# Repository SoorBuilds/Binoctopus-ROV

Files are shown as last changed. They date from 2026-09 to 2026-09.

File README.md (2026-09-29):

Screenshot 2026-09-12 at 11 26 09 PM

# Binoctopus-ROV

A stereoscopic underwater FPV drone

If you have ever wanted to explore the underwater world without getting wet, you can understand my motivation for designing this! I love the water and pretending to be a fish, but due to an ear problem I cant dive any deeper than 2m underwater :(
I knew I wanted to make an underwater drone to combat this issue, but none of the tutorials I could find online looked any good. They just WEREN'T IMMERSIVE! I set out to design a low budget, yet extremely immersive ROV and this design is my result so far. I expect it will need further iteration, but so far, My idea is to take two gopros and use them in webcam mode to stream 1080p60fps low latency up to the surface through a companion computer rasberry pi. Here is an image of the housing I designed for the gopros to be encased in an acrylic pipe with a custom 3d printed encap potted with epoxy for hypothetical pressure resistance up to 8.5 bar (85m underwater): 
Screenshot 2026-09-13 at 12 14 38 AM
But hold on... Why have two? 
After a ton of research into the cheapest way to get the best immersion on a tight budget, I discovered the Stereoscopic FPV community. FPV flying drone enthusiasts swear by a dual camera approach so that you can get depth perception, the same way that your two eyes do. By streaming the feed from one camera into one of the screens on a VR headset, and the right into the right for example, you would end up with a VERY natural feeling viewing experience, almost like looking through your own eyes.
Image of my oculus quest VR heasdet I will use to view the stereo video feeds:


Of course, this stereo vision needs to be paired with High resolution and low latency, both of which are usually very costly.
But there must be a cheap solution to this too... right?
Old Gopros! 
Old gopros are a proven low budget tool for high definition camera systems. They are able to handle all of the video compression by themselves and then transmit it either through WiFi or USB cable. Of course, for our underwater applications WiFi will not work, so cable it is.
Screenshot 2026-08-31 at 11 19 13 AM
Next up was the propulsion system!
For this i designed a custom thruster case to fit my 980kv sunnysky BLDC motors. I wanted to be able to just copy and paste the thrusters so that I could easily model the whole thing around the same repeating geometry. For this reason I decided to make it a the shape of a barrel that can easily be replaced if anything corrodes or breaks.



My test of the thruster at low speed in my bathroom sink:

https://github.com/user-attachments/assets/cb4b14ec-2ffa-4109-a6d4-e576eac1fb48

I want this drone to be as immersive as possible, it should feel like you are a fish!
This is why I decided to go with a vectored 6 degrees of freedom configuration. I tried to replicate the configuration from the FiFish v6, a $1700 ROV that manages to achieve 6 independant degrees of movement with only 6 motors!
Here is my attempt at replicating the configuration: 
Screenshot 2026-09-13 at 12 23 29 AM
Next up was the electronics!

Screenshot 2026-09-13 at 10 51 15 AM

This was the part I was dreading most and thankfully, I was able to find a good electronics schematic for a similiar project to what I was trying to do and I modified it to fit my design.
For the battery, I decided to go with a 3s3p custom pack using 9 lithium 18650 cells. Connected to the battery is a ____ A fuse and a pixhawk power sense module for extra safety.
For the Control system I went with the proven Pixhawk flight controller which allows me to control the complicated thruster configuration with ease through a program handled by the pixhawk. The pixhawk also reads the I2C protocol coming from a Depth sensor module which will come in very handy. Also, it acts as a safety mechanism allowing me to see the battery voltage, current draw, and it has a built in failsafe if the battery current goes too high.

Screenshot 2026-09-13 at 10 56 53 AM

The Rasberry pi is used as the companion computer to the pixhawk flight controller, it communicates through an ethernet cable to the surface computer giving the Camera feeds, depth information, power sensor information, IMU information, and temperature. 
To power the motors I use a 4 in 1 HackRC drone ESC and 2 single Littlebee ESCs, each channel is rated for 25A.
I also decided to mount a small 3d printer fan because these ESC's will get HOT!
Finally I wanted to include 4 LED's so I also mounted the drivers into the bottom of the configuration. 
Heres the power schematics i'm using
Screenshot 2026-09-27 at 6 01 12 PM

The wires are then routed out of the 3d printed endcap, soldered together and then the solder joint is potted in epoxy for maximum pressure rating, then the ethernet cable goes into a WEIPU female connector to attach to the ethernet cable tether going up to the surface!

Thats about it for the electronics
After designing this I went through it with my friends dad who is an Electrical Engineer. He approved!

All of the electronics fit inside of a 80ID x 90OD acrylic pipe that is 320 mm long
The endcaps are 3d printed and the cables are passed through with solder joints to stop capilary action up the cable insulation. Then the whole endcap, cable joints included, is potted in epoxy 

Screenshot 2026-09-13 at 11 01 25 AM

The part I was most looking forward to as an aspiring designer was the shell:
Screenshot 2026-09-12 at 2 51 10 PM
This took me A LOT of time, about two weekends worth of not touching grass but I think it was worth it because the result is a hydrodynamic, easy to assemble (hopefully) very solid design that will print in a standard 256^3 mm 3d printer bed! 
The hardware needed for as
embly is minimal, about 50 m3 bolts and heat set m3 brass inserts 
As for the assembly, I designed it to be as easy as possible. All of the thrusters connect to the shell in 4 places so start by inserting heat set inserts into your thrusters, then screw
How the horizontal thrusters will screw into the shell:

https://github.com/user-attachments/assets/931fc479-a999-401c-849b-3841b58536d0

I also decided to go with a vectored LED lighting fixture for 4 5W LEDs that should give a wide floodlight when descending past the daylight or diving at night. These LEDs will not just be on or off, but they can be controlled by a PWM signal provided by the Pixhawk

Screenshot 2026-09-13 at 10 39 18 AM

The tether connects to the shell by a rear mounted WEIPU connector: 
Screenshot 2026-09-13 at 10 47 37 AM

Because the shell was too big to print in one piece, it divides nicely into a rear, and two halves of the front. Everything is secured with M3 screws that will make for a very sturdy connection between the different pieces: 

https://github.com/user-attachments/assets/647f90c3-3dfa-40e7-80a8-27e3c8544850

Thats it for the shell! 
For the software, I will just be using the standard Ardusub firmware downloaded onto the pixhawk flight controller, for the surface computer I will use QGround control to be able to control the whole thing with my PS4 controller and view the camera feeds in my oculus quest headset!

My personal BOM (what I need to build this, I have most if it already) [Binoctopus ROV V1 BOM - What I need BOM(2).csv](https://github.com/user-attachments/files/32712083/Binoctopus.ROV.V1.BOM.-.What.I.need.BOM.2.csv)

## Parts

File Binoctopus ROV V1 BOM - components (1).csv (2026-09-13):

 | Name | Cost per unit | Shipping to US | photo | primary source | source 2 | source 3
 | 3x Molex male connector 20pin + pins | 5.32 | 0.00 |  | https://www.amazon.com/Molex-Circuits-Receptacle-Terminals18-24-Mini-Fit/dp/B079DCBCBZ/ref=sr_1_4 | https://www.amazon.com/Molex-Circuits-Receptacle-Terminals18-24-Mini-Fit/dp/B079DCBCBZ | https://s.click.aliexpress.com/e/_omMvDhG
 | 2x big oring (80 OD X 70 ID) | 5.75 | 4.44 |  | https://www.aliexpress.us/item/3256801511930688.html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 | https://s.click.aliexpress.com/e/_DBGTF93 | https://www.amazon.com/Mr-Ring-5X60-Metric-Viton/dp/B091B9QRPZ
 | acrylic pipe 80x70mm 250mm length | 55.00 | 18.48 |  | https://www.ebay.com/itm/358193843642?_skw=acrylic+tube&itmmeta=01KXMQHSF01GY1WHCQRDGK03KN |  | for some EU countries
 | Gopro Hero 12 x 2 on facebook marketplace | 250.00
 | USB C breakout board | $8 | 0.00 | 0.00 | https://www.amazon.com/MTDELE-Connector-Adapter-Breakout-Compatible/dp/B0F3WWTX78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 | https://www.amazon.com/MTDELE-Connector-Adapter-Breakout-Compatible/dp/B0F3WWTX78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
 | Cooling fan | 12.00 |  |  | https://www.aliexpress.us/item/2251832621295326.html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
 | Pressure sensor GY-MS5837 | 19.47 | 0.00 |  | https://s.click.aliexpress.com/e/_DelXMPr | https://s.click.aliexpress.com/e/_DlrplMZ | https://www.amazon.com/GY-MS5837-Waterproof-Pressure-Sensor-Module/dp/B09MKL4G1Y
 | 6x Sunnysky motor (980KV) | 80.00 | 0.00 |  | https://s.click.aliexpress.com/e/_DcYTy0v | slightly faster delivery | https://s.click.aliexpress.com/e/_DEd4fLL
 | 12x 5 gram metal weights | 1.80 | 0.00 |  | https://s.click.aliexpress.com/e/_DFjnm9J | https://www.amazon.com/Supply-Steel-Stick-Wheel-Weights/dp/B0068EQ9W0 | https://s.click.aliexpress.com/e/_DEcy23n
 | 2x 5W/3W LED on PCB (~6000K) | 3.00 | 0.00 |  | https://s.click.aliexpress.com/e/_oBrhtF0 | https://s.click.aliexpress.com/e/_DEqdHEt | https://s.click.aliexpress.com/e/_opHiULM
 | 2x waterproof LED lens (90 degree) | 4.47 | 2.32 |  | for US | for US (not tested) | https://s.click.aliexpress.com/e/_DlTtKAv
 | Buoyancy foam (10mm) | 4.27 | 0.00 |  | https://s.click.aliexpress.com/e/_okNslAm | https://s.click.aliexpress.com/e/_onDBJWZ | https://s.click.aliexpress.com/e/_DFa69R7
 | 9x 18650 batteries | 10.74 | 18.96 |  | https://s.click.aliexpress.com/e/_okgFG0t | https://www.18650batterystore.com/products/samsung-25r-18650 | https://www.tme.com/ux/en-us/details/accu-inr18650-25r/rechargeable-batteries/samsung-sdi/inr-18650-25r/ | this one needs to be disassembled
 | BLS connector (Dupont) 2x20 | 1.85 | 0.00 |  | https://s.click.aliexpress.com/e/_DcynHvJ | cheaper but longer delivery | https://s.click.aliexpress.com/e/_oF27AzW
 | BLS connector (Dupont) 1x4 | 2.02 | 0.00 |  | https://s.click.aliexpress.com/e/_DcynHvJ | also cheaper but longer delivery | https://s.click.aliexpress.com/e/_oF27AzW
 | 2x BLS connector (Dupont) 1x3 | 1.88 | 0.00 |  | https://s.click.aliexpress.com/e/_DcynHvJ | also cheaper but longer delivery | https://s.click.aliexpress.com/e/_oF27AzW
 | 8x BLS pin female (Dupont) | 1.55 | 0.00 |  | https://s.click.aliexpress.com/e/_DcynHvJ | cheaper but longer delivery | https://s.click.aliexpress.com/e/_oF27AzW
 | ESC 4in1 (25A+) | 31.75 | 0.00 |  | https://s.click.aliexpress.com/e/_oo4KMif | https://s.click.aliexpress.com/e/_DdPK3vJ | https://s.click.aliexpress.com/e/_DFZhoo1
 | 2 x ESC 1in1 (30A+) | 4.81 | 0.00 |  | https://s.click.aliexpress.com/e/_DkRcx6d | https://www.amazon.com/Accessories-LittleBee-BLHeli_S-Controller-Support/dp/B089ZTJ7L9 | https://www.aliexpress.com/item/2255800001568515.html
 | Raspberry Pi 3B/4B/5 | 63.33 | 0.00 |  | AliEx for US | https://s.click.aliexpress.com/e/_okIBPdi | https://www.amazon.com/dp/B07TD43PDZ/ref=twister_B07TN34PCN?_encoding=UTF8&psc=1
 | Heatsinks for Raspberry Pi | 1.23 | 0.00 |  | https://s.click.aliexpress.com/e/_oEb5EHe | https://s.click.aliexpress.com/e/_olcqT7T | https://s.click.aliexpress.com/e/_oDKnmwz
 | Fuse 80A | 2.70 | 0.00 |  | https://s.click.aliexpress.com/e/_DCVjoeV | https://s.click.aliexpress.com/e/_DEV8WDJ | https://s.click.aliexpress.com/e/_De5gVQd
 | Pixhawk | 83.43 | 0.00 |  | https://s.click.aliexpress.com/e/_olQjRWl | https://s.click.aliexpress.com/e/_DdTW9Zr | https://s.click.aliexpress.com/e/_om4QWzx
 | Pixhawk Power module | 4.16 | 0.00 |  | https://s.click.aliexpress.com/e/_DlLL5cl | https://s.click.aliexpress.com/e/_DdJPDBP | https://s.click.aliexpress.com/e/_oE4LCPf
 | 4x LED driver (3W) | 1.56 | 0.00 |  | https://s.click.aliexpress.com/e/_DdCBRCv | https://www.aliexpress.com/item/2251832638960124.html | https://www.aliexpress.us/item/3256807371606668.html?scm_id=1007.40196.436742.0&scm-url=1007.40196.436742.0
 | Micro-SD card 16GB | 4.83 | 1.99 |  | https://s.click.aliexpress.com/e/_DEIyz3R | https://www.amazon.com/SanDisk-2-Pack-microSDHC-Memory-2x32GB/dp/B08GY9NYRM | https://s.click.aliexpress.com/e/_on4A1ud
 | USB type A connector | 6.99 | 0.00 |  | https://www.amazon.com/SJZBIN-Breakout-Adapter-Female-Socket/dp/B09N8X9N4Y/ref=sr_1_8 | local electronics store | https://www.aliexpress.us/item/2251832738470618.html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:
 | MOSFET IRF1404 | 2.19 | 0.00 |  | https://s.click.aliexpress.com/e/_olPmgFO | https://s.click.aliexpress.com/e/_oFIoTs9 | local electronics store
 | Aluminium plate piece (3mm thick) | 1.87 | 0.00 |  | https://s.click.aliexpress.com/e/_DdBXwm9 | local hardware store | https://s.click.aliexpress.com/e/_olQd5Df
 | 10KΩ resistor | 1.29 | 0.00 |  | https://s.click.aliexpress.com/e/_Den9DVf | local electronics store | https://s.click.aliexpress.com/e/_oD3DUIz
Tether & charger | WEIPU Connector male (WF-16 TE 10pin) | 4.64 | 13.11 |  | https://www.elecbee.com/en-47827-10pin-te-male-plug-wf16-straight-plug-with-metal-clamping-nut-waterproof-connector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 | https://www.ebay.com/itm/276726435926 | cheapest option
 | WEIPU Connector female (WF-16 ZM 10pin) | 3.86 |  |  | https://www.elecbee.com/en-47893-round-flange-panel-socket-female-receptacle-zm-10pin-wf16-aviation-waterproof-connector | https://www.ebay.com/itm/276726435926 | cheapest option
 | WEIPU Connector male (WF-16 TI 10pin) | 3.93 |  |  | https://www.elecbee.com/en-47884-10pin-ti-male-plug-wf16-with-cable-clamping-plates-straight-plug-waterproof-connector | https://www.ebay.com/itm/276512789882 | cheapest option
 | Charger for 3S Battery | 39.00 | 0.00 |  | https://www.amazon.com/Battery-Balance-Charger-Discharger-Digital/dp/B0F6MP2Q5D/ref=sr_1_8 | expensive but very useful charger | https://s.click.aliexpress.com/e/_DlFG0HB
 | charger cable (4 wire JST-XH) | 3.20 | 0.00 |  | https://s.click.aliexpress.com/e/_DlCAinB | https://s.click.aliexpress.com/e/_DEqOxs1 | https://s.click.aliexpress.com/e/_DFSsINf
Surface control | PS4 controller knockoff | 26.97 | 0.00 |  | https://s.click.aliexpress.com/e/_onezo6d | https://s.click.aliexpress.com/e/_oFRzCvb | https://www.amazon.com/Sony-PlayStation-Dualshock-Wireless-Controller-Black/dp/B00D82Z4YO
 | Computer
Supplies |  | #REF! | #REF!
 | BOM :

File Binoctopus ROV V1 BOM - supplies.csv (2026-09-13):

 | name | amount | cost of a unit ($) 💵 | shipping to US ($) ✈️ | photo 🖼️ | primary source | other source 1 | other source 2 | description 📝
Miscellaneous | silicone grease | 2g | 2.32 | 0.00 |  | local hardware shop | https://s.click.aliexpress.com/e/_Dl6oYzF | https://s.click.aliexpress.com/e/_omPdcPA | You only need 1 pcs. This will be used for o-ring lubrication. |  | #REF!
 | soldering wire | 1 roll | 3.44 | 0.00 |  | local hardware shop | https://s.click.aliexpress.com/e/_DmMH3U5 | https://s.click.aliexpress.com/e/_oodYi8C | You need this to solder. |  | #REF!
 | solder wick | some | 1.88 | 0.00 |  | local hardware shop | https://s.click.aliexpress.com/e/_DEpHWbJ |  | Pick the 4mm width option. You need this for soldering as well. |  | #REF!
 | Epoxy | 120g total | 25.00 | 0.00 |  | https://www.amazon.com/Gallon-Resistant-Crystal-Coating-Casting/dp/B0D264VMQZ/ref=sr_1_1_sspa | https://www.amazon.com/Crystal-Non-Toxic-Scratching-Yellowing-Tumblers/dp/B086GFRS4C | https://s.click.aliexpress.com/e/_oneUbji | https://s.click.aliexpress.com/e/_DmQdPBF | Depending of which epoxy you buy, you will need to mix the components in different ratios. This Epoxy is used to seal various connections in the drone, like the 3D printed Endcaps and sealing electrical connections. | #REF!
 | 1-minute epoxy | 6g | 2.54 | 0.00 |  | local hardware shop | https://s.click.aliexpress.com/e/_olqLLbE | https://s.click.aliexpress.com/e/_DezfTQj | https://s.click.aliexpress.com/e/_DkGXzDh |  | #REF!
 | Heat-shrink black 6mm | 1m | 2.95 | 0.00 |  | https://s.click.aliexpress.com/e/_oECQU52 | https://s.click.aliexpress.com/e/_DEWErfT | local hardware shop |  |  | #REF!
 | Heat-shrink black 3mm | 1m | 2.26 | 1.42 |  | https://s.click.aliexpress.com/e/_oECQU52 | https://s.click.aliexpress.com/e/_DEWErfT | local hardware shop |  |  | #REF!
 | Heat-shrink yellow/green 2.5mm | 1m | 1.81 | 0.00 |  | https://s.click.aliexpress.com/e/_omENBws | https://s.click.aliexpress.com/e/_DCrXrS1 | local hardware shop |  |  | #REF!
 | Heat-shrink orange or red 2.5mm | 1m | 1.74 | 0.00 |  | https://s.click.aliexpress.com/e/_omENBws | https://s.click.aliexpress.com/e/_Dmns4Uv | local hardware shop |  |  | #REF!
 | Insulation tape | 1 roll | 1.41 | 0.00 |  | local hardware shop | https://www.aliexpress.com/item/3256803342798839.html | https://s.click.aliexpress.com/e/_oC5MwjW |  |  | #REF!
 | hot glue | some | 2.89 | 0.00 |  | local hardware shop | https://s.click.aliexpress.com/e/_DBR7uqd | https://www.aliexpress.us/item/2251832826380439.html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: |  |  | #REF!
 | zip-ties | 5x | 1.21 | 0.00 |  | local hardware shop | https://s.click.aliexpress.com/e/_DBvxny5 | https://s.click.aliexpress.com/e/_opvbQXq |  |  | #REF!
 | thread lock 243 (blue) | a little | 1.84 | 0.00 |  | local hardware shop | https://s.click.aliexpress.com/e/_DcGGaTn | https://s.click.aliexpress.com/e/_ood3Bfa |  |  | #REF!
 | thermal paste | a little | 2.06 | 0.00 |  | local hardware shop | https://s.click.aliexpress.com/e/_DBCxKOz | https://s.click.aliexpress.com/e/_omtXGVK |  |  | #REF!
 | solder heat-shrink red (waterproof) | 45 | 3.73 | 2.33 |  | https://s.click.aliexpress.com/e/_DFYb3pR |  |  |  |  | #REF!
 | solder heat-shrink white (waterproof) | 16 | 1.87 |  |  | https://s.click.aliexpress.com/e/_DmC6wE9 |  |  |  |  | #REF!
 | PLA filament | 1488g | 36.00 | 0.00 |  | Prusa Filament PLA | Bambulab Filament PLA | https://s.click.aliexpress.com/e/_Ddm0pSl | https://s.click.aliexpress.com/e/_DlK2eVn |  | #REF!
 | PET-G filament | 200g | 10.00 | 0.00 |  | Prusa Filament PETG | Bambulab Filament PETG | https://s.click.aliexpress.com/e/_DnaMakz |  |  | #REF!
 | cable braid 4mm | 20cm max | 1.48 | 0.00 |  | https://s.click.aliexpress.com/e/_DBu4SNT | https://s.click.aliexpress.com/e/_oFrg1tq | local hardware shop |  |  | #REF!
 | M3 Nuts and Bolts |  |  |  |  | https://www.amazon.com/iExcell-Stainless-Metric-Socket-Washers/dp/B0812TYT5L/ref=sr_1_4
 | glue stick/double side tape |  | 1.00 | 0.00 |  | local hardware shop |  |  |  |  | #REF!
Cables | CAT6 ethernet cable | 40m | 20.77 | 0.00 |  | https://www.aliexpress.us/item/3256804948964898.html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 | more expensive, but definitely will work, because they say it's a stranded core | https://allegro.pl/oferta/kabel-instalacyjny-linka-cat-6-u-utp-cca-100m-14013301395 |  |  | #REF!
 | CAT6 ethernet cable | 1m | 1.77 | 0.00 |  | https://s.click.aliexpress.com/e/_DeSxagB | https://s.click.aliexpress.com/e/_EzQRcBV |  |  |  | #REF!
 | USB C breakout board | 2 | 8.00 | 0.00 |  | https://www.amazon.com/MTDELE-Connector-Adapter-Breakout-Compatible/dp/B0F3WWTX78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
 | USB cable - Pixhawk | 0.15m | 1.38 | 0.00 |  | https://s.click.aliexpress.com/e/_Dd5Sy7J | https://pl.aliexpress.com/item/1005007471071240.html?scm_id=1007.40196.442820.0&scm-url=1007.40196.442820.0 |  |  |  | #REF!
 | jumper wire (male to male) | 2x | 2.14 | 0.00 |  | https://s.click.aliexpress.com/e/_DmS5sY1 | local electronics store |  |  |  | #REF!
 | 28AWG flat cable (4 strand) | 1.21 m | 0.94 | 1.03 |  | https://s.click.aliexpress.com/e/_DF0erLF | https://s.click.aliexpress.com/e/_DFGtDCH | https://s.click.aliexpress.com/e/_DkEX87P |  |  | #REF!
 | 20AWG Red black silicone cable pair | 9.41 m | 4.32 | 3.36 |  | https://www.aliexpress.us/item/3256801546041992.html?curPageLogUid=ldUpIKAgMQDk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 | https://s.click.aliexpress.com/e/_DmF9A9F | https://s.click.aliexpress.com/e/_DenJz5F |  |  | #REF!
 | 12AWG black silicone cable | 0.31 m | 2.26 | 0.00 |  | https://www.aliexpress.us/item/3256801546041992.html?curPageLogUid=ldUpIKAgMQDk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 | https://s.click.aliexpress.com/e/_DdyxtPT | https://s.click.aliexpress.com/e/_DenJz5F |  |  | #REF!
 |  |  |  |  |  |  |  |  |  |  | #REF!
 |  |  |  |  |  |  |  |  |  |  | #REF!
 |  |  |  |  |  |  |  |  |  |  | #REF!
 |  |  |  |  |  |  |  |  |  |  | #REF!
 |  |  |  |  |  |  |  |  |  |  | #REF!
 |  |  |  |  |  |  |  |  |  |  | #REF!
 |  |  |  |  |  |  |  |  |  |  | #REF!
 |  |  |  |  |  |  |  |  |  |  | #REF!
 |  |  |  |  |  |  |  |  |  |  | #REF!
 |  |  |  |  |  |  |  |  |  |  | #REF!
 |  |  |  |  |  |  |  |  |  |  | #REF!

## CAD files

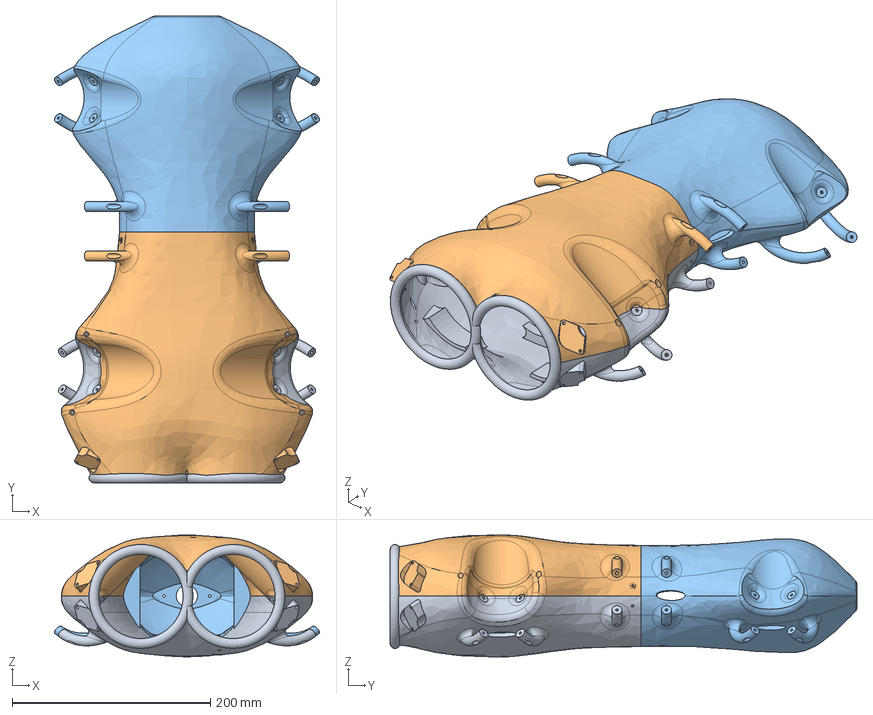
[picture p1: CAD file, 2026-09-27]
Shell.step
267.7 x 471.5 x 123.1 mm

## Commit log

2026-09-13 Enhance README with project details and images
    Expanded project description with details on design motivation, camera setup, propulsion system, electronics, and assembly.
2026-09-13 Revise README.md with updated project details
    Updated images and content for the Binoctopus-ROV project, including details on the propulsion system, electronics, and assembly instructions.
2026-09-13 Revise BOM for Binoctopus ROV V1 components
    Updated the Bill of Materials (BOM) for the Binoctopus ROV V1, including new components and links.
    [Binoctopus ROV V1 BOM - components .csv]
2026-09-27 Update README with propulsion system details and images
    Added images and details about the propulsion system, thruster testing, power schematics, and electronics housing.
2026-09-27 Add personal BOM link to README
    Added personal BOM link for building the project.
2026-09-27 Added the STEP file for the shell of my ROV
    [Shell.step]
2026-10-22 Add journal entries for Binoctopus ROV V1
    Documented the design and development process of the Binoctopus ROV V1, including thruster designs, housing for GoPros, and shell construction.
2026-10-22 Rename Configuration 1.step.zip to BINOCTUPUS CAD.zip
2026-10-22 Rename Binoctopus ROV V1 BOM - components (1).csv to bom/components.csv
2026-10-22 Rename Binoctopus ROV V1 BOM - supplies.csv to bom/supplies.csv
2026-10-22 Rename bom/components.csv to bom/Bill of Materials/components.csv
2026-10-22 Rename bom/supplies.csv to bom/Bill of Materials/supplies.csv
2026-10-22 Rename bom/Bill of Materials/components.csv to Bill of Materials/Components.csv
2026-10-22 Rename bom/Bill of Materials/supplies.csv to Bill of Materials/Supplies.csv
2026-10-22 Add Binoctopus CAD 3D model file
2026-10-22 Rename 3d Models/Battery holder clamp.stl to 3d Models/STL files/Battery holder clamp.stl
2026-10-22 Rename 3d Models/Cable Endcap part 1.stl to 3d Models/STL files/Cable Endcap part 1.stl
2026-10-22 Rename 3d Models/Cable Endcap part 2.stl to 3d Models/STL files/Cable Endcap part 2.stl
2026-10-22 Rename 3d Models/Connector mount.stl to 3d Models/STL files/Connector mount.stl
2026-10-22 Rename 3d Models/Fan Mount.stl to 3d Models/STL files/Fan Mount.stl
2026-10-22 Rename 3d Models/Front Belly.stl to 3d Models/STL files/Front Belly.stl
2026-10-22 Rename 3d Models/Front Hat.stl to 3d Models/STL files/Front Hat.stl
2026-10-22 Rename 3d Models/LED mount.stl to 3d Models/STL files/LED mount.stl
2026-10-22 Rename 3d Models/Left Gopro Endcap Part 1.stl to 3d Models/STL files/Left Gopro Endcap Part 1.stl
2026-10-22 Rename 3d Models/Left Gopro Endcap Part 2.stl to 3d Models/STL files/Left Gopro Endcap Part 2.stl
2026-10-22 Rename 3d Models/Molex mount part 1.stl to 3d Models/STL files/Molex mount part 1.stl
2026-10-22 Rename 3d Models/Molex mount part 2.stl to 3d Models/STL files/Molex mount part 2.stl
2026-10-22 Rename 3d Models/Molex mount part 3.stl to 3d Models/STL files/Molex mount part 3.stl
2026-10-22 Rename 3d Models/Molex mount part 4.stl to 3d Models/STL files/Molex mount part 4.stl
2026-10-22 Rename 3d Models/Pixhawk stand.stl to 3d Models/STL files/Pixhawk stand.stl
2026-10-22 Rename 3d Models/Rasberry Pi mount bracket.stl to 3d Models/STL files/Rasberry Pi mount bracket.stl
2026-10-22 Rename 3d Models/Rear Body.stl to 3d Models/STL files/Rear Body.stl
2026-10-22 Rename 3d Models/Rear Endcap part 2.stl to 3d Models/STL files/Rear Endcap part 2.stl
2026-10-22 Rename 3d Models/Rear endcap pt1.stl to 3d Models/STL files/Rear endcap pt1.stl
2026-10-22 Rename 3d Models/Right Gopro Endcap Part 1.stl to 3d Models/STL files/Right Gopro Endcap Part 1.stl
2026-10-22 Rename 3d Models/Right Gopro Endcap Part 2.stl to 3d Models/STL files/Right Gopro Endcap Part 2.stl
2026-10-22 Rename 3d Models/Thruster Body.stl to 3d Models/STL files/Thruster Body.stl
2026-10-23 Update README with additional source code links
    Added links to source code for BLHeli_S, BlueOS, and QGroundControl. Mentioned that motors are flashed with BLHeli_S for reverse spinning.
